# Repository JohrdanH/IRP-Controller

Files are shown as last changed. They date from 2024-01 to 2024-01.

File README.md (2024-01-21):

# Inverted Rotary Pendulum

## Overview

Welcome to the "Inverted Rotary Pendulum" GitHub repository! This project focuses on implementing a State Space feedback controller to stabilize an inverted Rotary Pendulum around its upward position using Arduino. Additionally, the repository includes a simulation of the inverted rotary pendulum with the controller in Simulink and code to estimate the parameters of the DC motor.

## Contents

1. [Arduino Code](#arduino-code)
2. [Simulink Simulation](#simulink-simulation)
3. [DC Motor Parameter Estimation](#dc-motor-parameter-estimation)

## Arduino Code

The `SS_Feedback_Controller` directory contains the source code written in Arduino for implementing the State Space feedback controller. The controller is designed to stabilize the inverted Rotary Pendulum, maintaining its equilibrium position.

### Instructions

To run the Arduino code:
1. Open the Arduino IDE.
2. Create a new project.
3. Copy and paste the code from the `SS_Feedback_Controller` directory into the Arduino IDE.
4. Connect your Teensy 4.0 board and upload the code.

## Simulink Simulation

The `Simulation of IRP Control` directory includes a Simulink model for simulating the behavior of the inverted rotary pendulum with the implemented State Space feedback controller. This simulation provides insights into the system's dynamics and the controller's effectiveness.

### Instructions

To run the Simulink simulation:
1. Open MATLAB and navigate to the `Simulation of IRP Control` directory.
2. Open the Simulink model file using the instructions given in the Readme file.
3. Run the simulation to visualize the behavior of the inverted rotary pendulum under the State Space feedback control.

## DC Motor Parameter Estimation

In the `Estimation of DC Motor Parameters` directory, you will find code related to the estimation of DC motor parameters. Accurate motor parameters are crucial for the proper functioning of the feedback controller. This code helps in identifying and setting the necessary motor parameters.

### Instructions

To estimate DC motor parameters:
1. Navigate to the `Estimation of DC Motor Parameters` directory.
2. Run the parameter estimation code using the instructions given in the Readme file to determine the DC motor parameters.

## Contributing

If you find any issues or have suggestions for improvements, feel free to contribute! Fork the repository, make your changes, and submit a pull request.

## License

This project is licensed under the [MIT License](LICENSE), allowing for open collaboration and sharing.

Feel free to explore the project, learn from it, and adapt it to your needs. Happy coding! 🚀

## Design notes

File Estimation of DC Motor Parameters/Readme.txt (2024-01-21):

This files are used to estimate the DC Motor parameters
using the Parameter Estimator App of MATLAB.

For this, I used the Teensy 4.0 and an Excel macro (https://www.parallax.com/package/plx-daq/)
to read the DC motor speed during 10 seconds
with a sample period of 10 ms. With the macro,
you get a table of time, speed and voltage that
is introduced in the Parameter Estimator App
to estimate the DC motor Parameters.

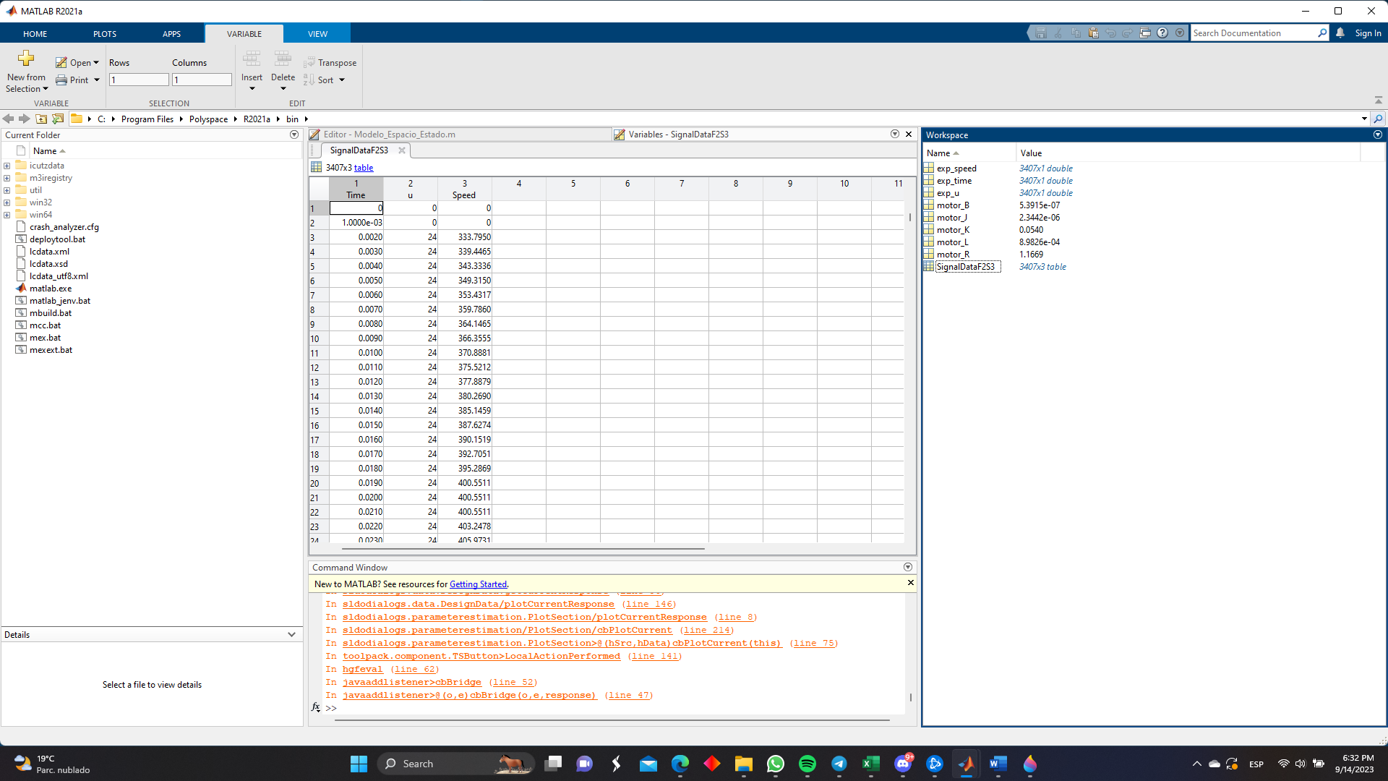
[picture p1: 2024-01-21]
Estimation of DC Motor Parameters/Par_Est3.png

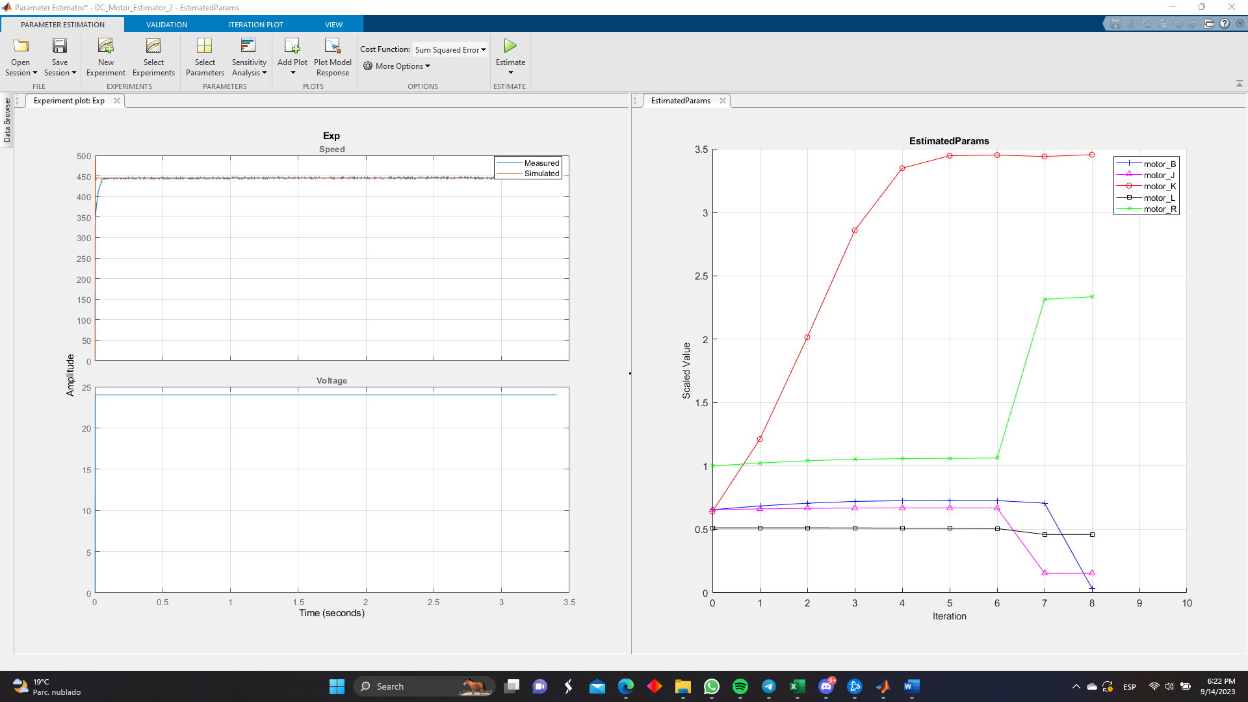
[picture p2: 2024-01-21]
Estimation of DC Motor Parameters/Par_Est.png

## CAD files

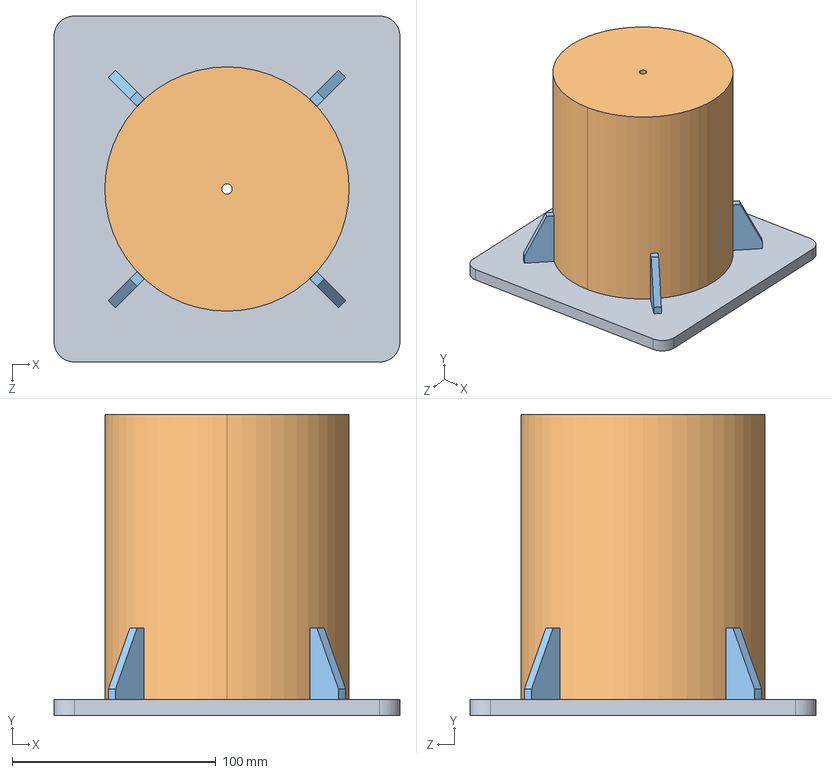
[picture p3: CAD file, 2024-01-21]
Simulation of IRP Control/PF_M1_Base_Default_sldprt.STEP
170.0 x 148.0 x 170.0 mm

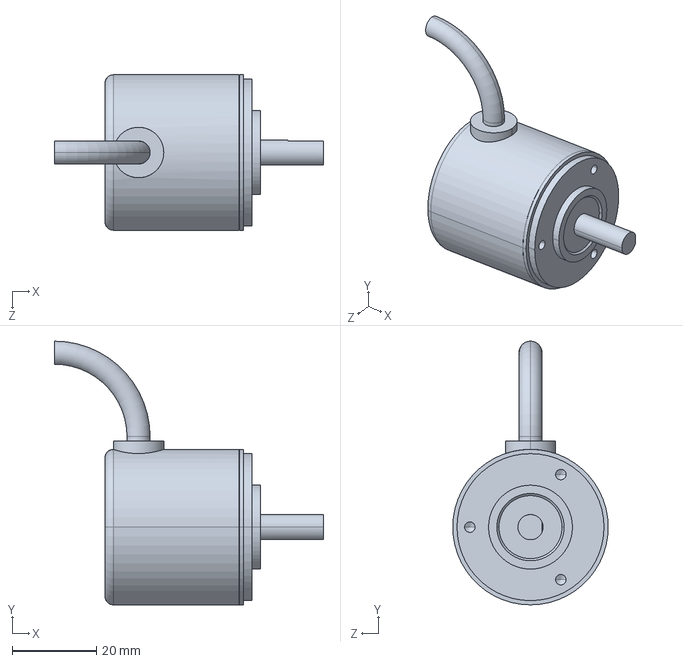
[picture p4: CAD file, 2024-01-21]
Simulation of IRP Control/DELTA - ES3-01PG6941 - Incremental Rotary Encoder_Default_sldprt.STEP
64.0 x 62.8 x 37.0 mm

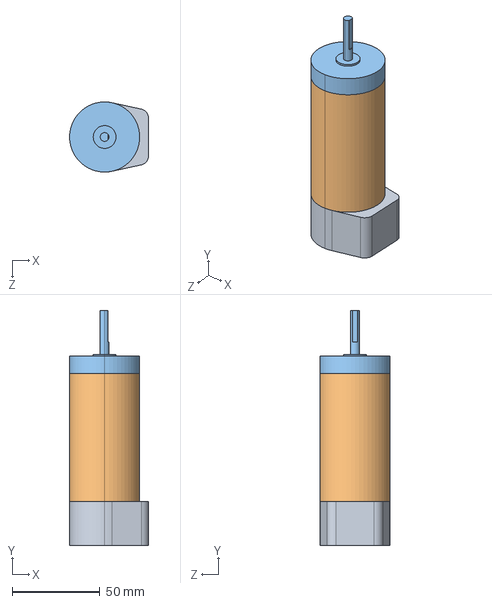
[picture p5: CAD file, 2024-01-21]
Simulation of IRP Control/DC Motor_Predeterminado_sldprt.STEP
45.0 x 134.0 x 40.0 mm

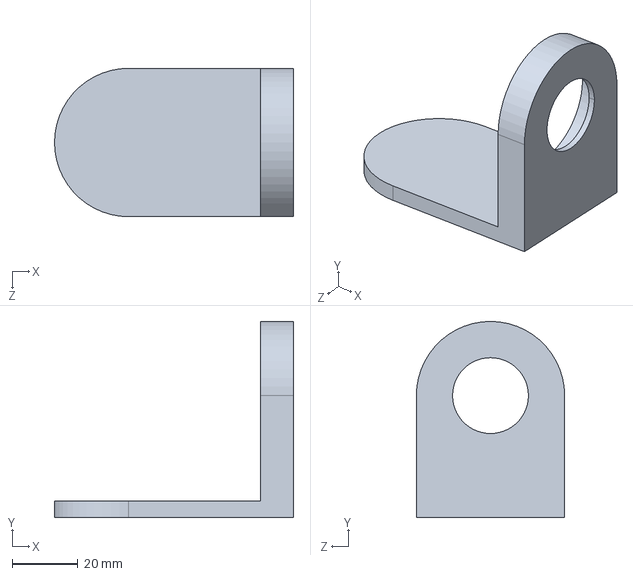
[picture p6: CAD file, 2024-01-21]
Simulation of IRP Control/P2_Predeterminado_sldprt.STEP
72.5 x 59.5 x 45.0 mm

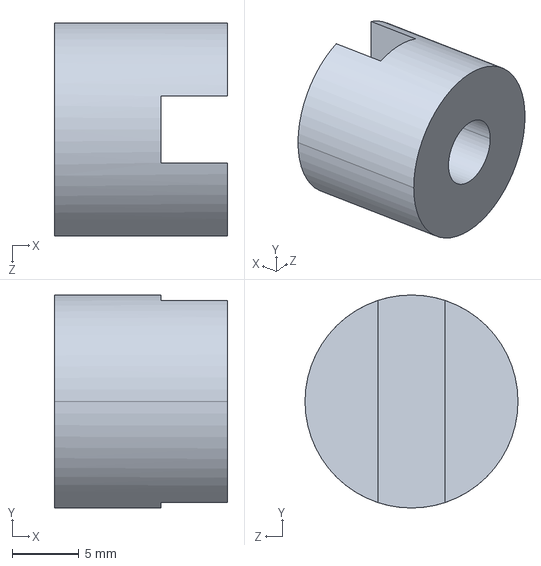
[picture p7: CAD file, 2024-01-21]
Simulation of IRP Control/PF_M1_Acople_Default_sldprt.STEP
13.0 x 16.0 x 16.0 mm

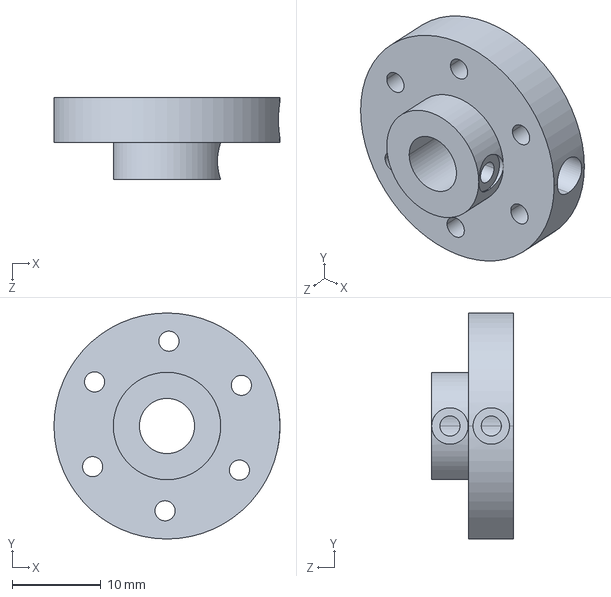
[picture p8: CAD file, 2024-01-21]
Simulation of IRP Control/Mounting Hub_Default_sldprt.STEP
25.4 x 25.4 x 9.21 mm

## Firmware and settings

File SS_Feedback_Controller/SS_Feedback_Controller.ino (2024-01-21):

/*
  Stabilization of an Inverted Rotary Pendulum
  using a State-Space Feedback Controller
  around its upward position

  Hardware:
  - Teensy 4.0
  - Motor driver for two motors in a designed PCB
  - DC Motor 24V 3000 RPM with Encoder 100 pulses per revolution
  - Encoder 5V 1024 pulses per revolution with 2 channels (A,B)
  - Steel Rod
  - Mechanical Structure made with 3D Printer

*/

#define ENCAM1 2 // Channel A of Encoder 100 PPR
#define ENCBM1 3 // Channel B of Encoder 100 PPR
#define ENCAM2 4 // Channel A of Encoder 1024 PPR
#define ENCBM2 5 // Channel B of Encoder 1024 PPR
#define INA 7 // Timer FlexPWM1.3 - PWM Output to DC Motor CW direction
#define INB 8 // Timer FlexPWM1.3 - PWM Output to DC Motor CCW direction

//Gains K1, K2, K3, K4
//
//double K1 =  -0.679823287396430; //Gains calculated using pole placement with SP = 20% Ts = 4s
//double K2 =  -0.906954547193577;
//double K3 =  -14.7265763767098;
//double K4 =  -1.35643669788940;

//double K1 =  -0.299143366874695; //Gains calculated using pole placement with SP = 5% Ts = 4s
//double K2 =  -0.851790602386917;
//double K3 =  -15.3274699001836;
//double K4 =  -1.30654012868679;

double K1 =  -0.945438131445806; //Gains calculated using pole placement with SP = 5% Ts = 3s
double K2 =  -1.30374175390291;
double K3 =  -18.2714824178363;
double K4 =  -2.06633632968468;

double Ki =  60;

double Ts = 0.001;

double u = 0; 

double pos1 = 0;
double prev_pos1 = 0;
double pos2 = 0;

double phi = 0; // Angular Position of DC Motor Shaft
double theta = 0; // Angular Position of Steel Rod
double phi_dot = 0; // Angular Velocity of DC Motor Shaft
double theta_dot = 0; // Angular Velocity of Steel Rod

double phi_1 = 0;
double theta_1 = 0;
double phi_dot_1 = 0;

double z = 0;
double z_1 = 0;

long int prevT = micros();
float prev_Th = 0;

long prev_timestamp_us = micros();
long pulse_timestamp = 0;
long prev_pulse_timestamp = 0;
long pulse_timestamp2 = 0;
long prev_pulse_timestamp2 = 0;
int dir = 0; // Direction of DC Motor CW = 0 | CCW = 1
int s = 0;
int pwmOut = 0;

void setup() {
  Serial.begin(128000);
  pinMode(ENCAM1, INPUT);
  pinMode(ENCBM1, INPUT);
  pinMode(ENCAM2, INPUT);
  pinMode(ENCBM2, INPUT);
  attachInterrupt(digitalPinToInterrupt(ENCAM1),readEncoder1,RISING);
  attachInterrupt(digitalPinToInterrupt(ENCAM2),readEncoder2,RISING);
  analogWriteFrequency(7, 36620); // Teensy 4.1 pin 8 also changes to 36.62 kHz, ideal for 12 bits resolution
  analogWriteResolution(12);
  Serial.println("LABEL,HORA,PHI_DOT");
  
}

void loop() {
  if(micros() - prevT > 1000){
      prevT = micros();

      z = z_1 - theta_1*Ts;
      theta_dot = (1/Ts)*theta - (1/Ts)*theta_1;
      
      u = - K1*phi - K2*phi_dot - K3*theta - K4*theta_dot - Ki*z; // Add -Ki*z to include integral action

      if(u > 24){
        u = 24;
        s = 1;
      }
      if(u < -24){
        u = -24;
        s = -1;
      }
      pwmOut = map(abs(u),0,24,600,4095); // DC Motor dead zone: It starts moving at a value of 600 
      
      if(u >= 0){
        dir = 1;
        
      }
      else{
        dir = 0;
      }

      if(theta > -0.73 && theta < 0.73){ // Stabilization range 
        if(dir == 1){
          analogWrite(INA,pwmOut);
          analogWrite(INB,0);
        }
        else if(dir == 0){
          analogWrite(INB,pwmOut);
          analogWrite(INA,0);
        }
      }
      else{
        analogWrite(INB,0);
        analogWrite(INA,0);
      }
      phi_1 = phi;
      theta_1 = theta;
      prev_pos1 = pos1;
      Serial.print("DATA,TIME,");
      Serial.println(phi_dot);
    }
}


void readEncoder1(){
  int b1 = digitalRead(ENCBM1);
  pulse_timestamp = micros();  
  float Ts = (pulse_timestamp - prev_pulse_timestamp) * 1e-6f; // Calculate transcurred time between pulses
  prev_pulse_timestamp = pulse_timestamp;
  
  if(b1>0){
    pos1++;
    phi_dot =  (2*PI/100.0)/Ts;
    if(phi_dot > 1000 || phi_dot < -1000){ // Remove outliers
      phi_dot = 0;
    }
  }
  else{
    pos1--;
    phi_dot =  -(2*PI/100.0)/Ts;
    if(phi_dot > 1000 || phi_dot < -1000){ // Remove outliers
      phi_dot = 0;
    }
  }
  
  phi = pos1*6.2832/100.0; // Experimental test: 100 pulses per revolution
  phi_dot_1 = phi_dot;
}

void readEncoder2(){
  int b2 = digitalRead(ENCBM2);
  pulse_timestamp2 = micros();  
  float Ts = (pulse_timestamp2 - prev_pulse_timestamp2) * 1e-6f; // Calculate transcurred time between pulses
  prev_pulse_timestamp2 = pulse_timestamp2;
  
  if(b2>0){
    pos2--;
    theta_dot =  -(2*PI/1024.0)/Ts; // rad/s
  }
  else{
    pos2++;
    theta_dot =  (2*PI/1024.0)/Ts; // rad/s
  }
  theta = pos2*6.2832/1024.0; // rad
}
